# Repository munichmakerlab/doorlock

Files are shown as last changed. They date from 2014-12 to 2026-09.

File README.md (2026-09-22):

# MuMaLab DoorLock

## Schema

```
                      +----+                                        
                      |    |                          +-----------+
                      |    |                          | RFID      | 
                      |    |                       +--+ Reader    | 
                      |    |                       |  +-----------+ 
  +--------------+    |    |    +---------------+  |                
  |              |    |    |    |               |  |  +-----------+ 
  | RaspberryPi  +----(UART)----+  Arduino      +--+--+ Keypad    | 
  |              |    |    |    |   (frontend)  |  |  +-----------+ 
  +------+-------+    |    |    +---------------+  |                
         |            |    |                       |  +-----------+ 
         |            |    |                       +--+ Display   | 
   +-----+------+     |    |                          +-----------+ 
   | Door lock  |     |    |                                        
   +------------+     |    |                                        
                      +----+                                        
```

## Doorlock editor

There is a terminal-based (TUI) management tool available as well. Check out the dedicated repository for details: [doorlock-edit](https://github.com/munichmakerlab/doorlock-edit)

## Database Management CLI

The backend ships with `backend/manage_db.py`, a small CLI helper around the `doorlock.db` SQLite database. It creates the schema on first run (by executing `doorlock.db.sql`) and offers person/token lifecycle tooling that mirrors the firmware expectations.

### Running the tool

``` bash
python backend/manage_db.py <entity> <action> [arguments]
```

- `entity`: `person` or `token`
- `action`: subcommand listed below
- Output is logged to stdout/stderr; tables leverage `prettytable`

### Person actions

| Action | Arguments | Description |
| --- | --- | --- |
| `create` | `name`, `group_id` | Adds a new member with `disabled=0` after ensuring the name is unique. |
| `remove` | `name` | Deletes the person record (and their tokens via FK constraints if configured). |
| `list` | – | Shows active and inactive members plus token counts using textual tables. |
| `enable` / `disable` | `name` | Toggles the `disabled` flag to allow/deny door access. |
| `rename` | `old_name`, `new_name` | Renames a person once uniqueness is verified. |
| `show` | `name` | Prints status (“ENABLED”/“DISABLED”) and enumerates stored tokens. |

Examples:

``` bash
# Create an active member in group 2
python backend/manage_db.py person create "Ada Lovelace" 2

# Disable temporary access
python backend/manage_db.py person disable "Ada Lovelace"
```

### Token actions

Tokens live on the `dl_tokens` table and are always tied to an existing person. PINs are stored as `sha256("<token>:<pin>")` hashes.

| Action | Arguments | Description |
| --- | --- | --- |
| `add` | `person`, `token`, `pin` | Verifies ownership, checks for duplicates, and inserts a token/PIN pair. |
| `reset` | `person`, `pin` | Re-hashes the stored PIN for the person’s sole token (multi-token reset is intentionally rejected). |
| `remove` | `token` | Removes the token entry after confirming it exists. |

Examples:

``` bash
# Link a RFID tag to Ada with PIN 0420
python backend/manage_db.py token add "Ada Lovelace" 12345678 0420

# Rotate the PIN for the only token Ada owns
python backend/manage_db.py token reset "Ada Lovelace" 8642
```

### Operational notes

- The script logs to the `manage_db` logger; use `--log-level DEBUG` via `PYTHONLOGGING` env if deeper tracing is required.
- Tables are auto-created the first time the script runs if `doorlock.db` is missing the required schema.
- Always run the CLI from the repository root so relative paths to `doorlock.db` and `doorlock.db.sql` resolve correctly.

## Membership Sync CLI

You can export a csv of the existing members by going to the google drive, "Finanzen und Mitglieder" -> "Mitglieder" and make sure you're on the first page of the sheet. Put that csv on the doorlockpi and run the script. The helper [backend/prune_cancelled_members.py](backend/prune_cancelled_members.py) enforces that `doorlock.db` only contains people from this csv, removing stragglers who should no longer have access.

### Usage

``` bash
python backend/prune_cancelled_members.py [--db path/to/doorlock.db] [--csv path/to/members.csv] [--dry-run] [--yes]
```

- Reads the CSV, builds full names (`Vorname` + `Name`), and treats that set as the source of truth.
- Prints members that appear in the CSV but not the database (for awareness) and highlights the active database entries that will be disabled. Already disabled members are ignored so they do not clutter the diff.
- Name matching is case-insensitive and normalizes umlauts/ß (`Söhnen` matches `Soehnen`, `Groß` matches `Gross`).
- When run without `--dry-run` or `--yes`, launches an interactive selector: use the arrow keys to move, `space` to toggle entries, and `Enter` to confirm.
- Use `--yes` to skip the selector and disable all stale members automatically.
- On confirmation it flips `dl_persons.disabled` to `1` for the selected entries (tokens remain but are unusable because the person is disabled).

## Rename Members CLI

For ad-hoc name corrections, use [backend/rename_members.py](backend/rename_members.py).

``` bash
python backend/rename_members.py [--db path/to/doorlock.db]
```

- TTY-only curses UI showing all members with status and token counts.
- Navigate with arrows, press `f` to search by name (case-insensitive), press `space` on a highlighted entry to rename: you will be prompted (outside the UI) for new last name, then first name, then confirmation showing old → new.
- If the name is unchanged or already taken, nothing is updated. Successful renames write directly to `dl_persons` and return you to the list.

Typical workflow:

``` bash
# Inspect differences without deleting
python backend/prune_cancelled_members.py --dry-run

# Apply the deletions after review
python backend/prune_cancelled_members.py --yes
```

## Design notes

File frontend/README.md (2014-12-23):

# Doorlock Frontend
Arduino-based frontend for the MuMaLab hackerspace doorlock.

It's supposed to use a LCD, a 3x4 keypad and a RFID reader. That's too much pins for the Arduino Uno, so for now, there's no LCD. Instead, display output is send to the serial port, which will later also be used for communication with the backend.

## Libraries
* RFID Reader: https://github.com/miguelbalboa/rfid
* Keypad: http://playground.arduino.cc/code/Keypad

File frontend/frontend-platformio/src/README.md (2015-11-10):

# Doorlock Frontend
Arduino-based frontend for the MuMaLab hackerspace doorlock.

It's supposed to use a LCD, a 3x4 keypad and a RFID reader.

## Libraries
* RFID Reader: https://github.com/miguelbalboa/rfid
* Keypad: https://github.com/Chris--A/Keypad

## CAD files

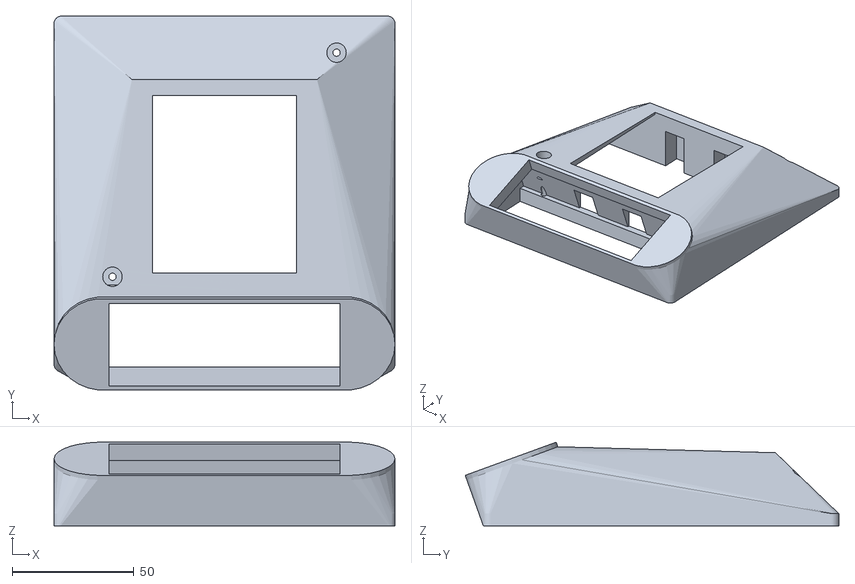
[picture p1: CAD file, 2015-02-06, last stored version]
OpenSCAD/EntrySystem.stl
140.0 x 153.4 x 34.3

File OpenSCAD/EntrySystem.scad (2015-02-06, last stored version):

$fn=30;

module visor(xdim, zdim, rdim) {
	hull() {
		translate([rdim, rdim, 0]) cylinder(r=rdim,h=zdim);
		translate([xdim-rdim,rdim,0]) cylinder(r=rdim,h=zdim);
	}
}

module baseplate(xdim_base,ydim_base,zdim_base,rdim_base) {	
	hull() {
		visor(xdim_base,zdim_base,rdim_base);
		translate([0,ydim_base,0]) visor(xdim_base,zdim_base,rdim_base);
	}
}

module keypad_part(xdim,ydim,zdim,length) {
	translate([length/2-xdim/2,length/2-ydim/2,0]) cube([xdim,ydim,zdim]);
}

module basebody() {
	hull() {
		hull() {
			baseplate(length,length,5,3);
			rotate([20,0,0]) visor(length,20,20);
		}
		keypad_part(76,100,30,length);
	}
	rotate([20,0,0]) visor(length,22,20);
}

module mounting_points() {
	translate([length/2-old_plate[0]/2,length/2-old_plate[1]/2+15,-1]) {
		cube(old_plate);
		
		translate([15,15,-10]) {
			cylinder(r=1.5,h=100);
			translate([0,0,30])
			cylinder(r=4,h=100);	
		}
	
		translate([old_plate[0]-15,old_plate[1]-15,-10]) {
			cylinder(r=1.5,h=100);	
			translate([0,0,25])
			cylinder(r=4,h=100);	
		}
	}
}

module rfid_reader() {
	
	rotate([-6,-40,0])
	translate([7,45,-25])
	cube([40,70,30]);

}

module rfid_hull(length) {
	color("red"){ 
		hull() {
			translate([7,43,0])
			cube([2,70.5,8]);
		
			translate([38.5,43,0])
			cube([2,70.5,2]);
		
			translate([40.5,43,27])
			cube([2,70.5,2]);
		}

		hull() {
			translate([length-7,43,0])
			cube([2,70.5,8]);
		
			translate([length-38.5,43,0])
			cube([2,70.5,2]);
		
			translate([length-40.5,43,27])
			cube([2,70.5,2]);
		}

	}
}


module display_cable_pipe() {
	translate([110,50,-1])
	rotate([90,0,0])
	cylinder(r=7,h=20);
}


length = 140;
keypad_size = [59,73,100];
keypad_mounting_space = [45,92,21];
keypad_mounting_space_center = [20,92,21];

display_size = [95,36,100];
display_mounting_space = [120,38,35.5];

old_plate = [122,122,1];

difference() {
	union() {
		difference() {
			basebody();
			translate([length/2-keypad_size[0]/2,length/2-keypad_size[1]/2+7,0]) cube(keypad_size);
		
			difference() {
				translate([length/2-keypad_mounting_space[0]/2,length/2-keypad_mounting_space[1]/2+7,0]) cube(keypad_mounting_space);
				translate([length/2-keypad_mounting_space_center[0]/2,length/2-keypad_mounting_space_center[1]/2+7,0]) cube(keypad_mounting_space_center);
			}
		
			translate([length/2-display_size[0]/2,2,0]) rotate([20,0,0]) translate([0,0,-20])
			cube(display_size);
		
			translate([length/2-display_mounting_space[0]/2,2,0]) rotate([20,0,0]) translate([0,0,-20])
			cube(display_mounting_space);
		
		}
	
	translate([0,36.5,0])
	cube([length,4,8]);
	}

	rfid_hull(length-2);
	mounting_points();
	//display_cable_pipe();	
}
	

	

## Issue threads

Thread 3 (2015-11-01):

Space open, but door locked -> Press key to open

tiefpunkt, 2015-11-01:
With the kids running in the hallway, and playing with our door, the current modus operandi is to just completely lock the door. This sort of contradicts our openness, so here's a different approach:

* We implement a third state of the door, let's call it "SEMI_LOCKED".
* Even though the space is technically open, the door remains locked.
* The door will unlock, when you press a certain key on the pinpad.
* The display shows a message reflecting this, and give instructions as to what to do to enter the space.

-> Kids won't be able to open the door as easy.
-> But still, people even without a token can come in easily.

peterfroehlich, 2015-11-02:
The "E" Button is still without a function (I wanted to implement a door
bell) and could be used for that...
Msg: "Press friEnd, and enter"
;-)

-P

2015-11-01 23:40 GMT+01:00 Severin Schols <notifications@github.com>:

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

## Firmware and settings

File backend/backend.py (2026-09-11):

#!/usr/bin/env python3
import sqlite3
import serial
from threading import Timer
import logging
import hashlib
import os.path
from time import sleep
from datetime import datetime, timedelta
from sys import exit
import paho.mqtt.client as paho

import config

DIR = os.path.dirname(os.path.realpath(__file__))

# config
DATABASE = DIR + '/doorlock.db'
SERIAL_PORTS = ['/dev/ttyUSB0', '/dev/ttyUSB1', '/dev/ttyUSB2', '/dev/ttyUSB3']
DEBUG = False
LOG_FILENAME = DIR + "/doorlock.log"
LOG_LEVEL = logging.INFO
PONG_TIMEOUT = 30  # in sec

if os.path.exists("COM8"):
    SERIAL_PORT = 'COM8'
    DEBUG = True

# regular ping to frontend, every 10 seconds, 30 sec timeout
running = True


def ping():
    if not running:
        return
    ser.write(b"PING;\n")
    ser.flush()
    timer = Timer(10.0, ping)
    timer.start()


def statusChange():
    if lock.isUnlocked():
        ser.write(b"STATUS,1;\n")
        mqttc.publish(config.topic, "1", 1, True)
    else:
        ser.write(b"STATUS,0;\n")
        mqttc.publish(config.topic, "0", 1, True)
    ser.flush()


def feedback(topic, state):
    mqttc.publish("%s/%s" % (config.feedback_topic, topic), str(state), 1, False)


def create_hash(text):
    h = hashlib.sha256()
    h.update(text.encode("utf-8"))
    return h.hexdigest()


def ring_doorbell():
    logger.info("Ring Ring")


def serial_connect():
    for serial_port in SERIAL_PORTS:
        if os.path.exists(serial_port):
            logger.info("Using serial port %s" % serial_port)
            return serial.Serial(serial_port, timeout=6)
    logger.error("No valid serial port found. Sleeping and retrying...")
    sleep(60)
    return serial_connect()


# MQTT functions
def on_connect(client, userdata, flags, reason_code, properties=None):
    logging.info("Connect with RC " + str(reason_code))


def on_disconnect(client, userdata, flags, reason_code, properties=None):
    logging.warning("Disconnected (RC " + str(reason_code) + ")")
    if reason_code != 0:
        try_reconnect(client)


# MQTT reconnect
def try_reconnect(client, time=60):
    try:
        logging.info("Trying reconnect")
        client.reconnect()
    except Exception:
        logging.warning("Reconnect failed. Trying again in " + str(time) + " seconds")
        Timer(time, try_reconnect, [client]).start()


# get logger
logging.basicConfig(format='%(asctime)s - %(name)s - %(levelname)s - %(message)s', level=LOG_LEVEL,
                    filename=LOG_FILENAME)
logger = logging.getLogger("doorlock")
logger.info("Starting doorlock backend")

# instantiate db connection
conn = sqlite3.connect(DATABASE)
c = conn.cursor()
logger.debug("Database opened")

# connect to serial port
ser = serial_connect()
logger.debug("Serial port to frontend opened")

# initialize MQTT
logging.info("Initializing MQTT")
mqttc = paho.Client(paho.CallbackAPIVersion.VERSION2, "mumalab_doorlock")
mqttc.username_pw_set(config.broker["user"], config.broker["password"])
mqttc.will_set(config.topic, "?", 1, True)
mqttc.on_connect = on_connect
mqttc.on_disconnect = on_disconnect
try:
    mqttc.connect(config.broker["hostname"], config.broker["port"], 60)
except Exception as e:
    logger.error("Failed to connect to MQTT! Got exception: %s" % str(e))
mqttc.loop_start()

# lock implementation
if DEBUG:
    from simlock import SimLock
    lock = SimLock()
else:
    # from motorlock import MotorLock
    # lock = MotorLock()
    from zuko_wifi_lock import ZukoLock
    lock = ZukoLock()

lock.onStatusChange += statusChange
lock.onFeedback += feedback

# start pinging frontend
last_successful_ping = datetime.now()
ping()


while True:
    try:
        a = ser.readline()
        if not a:
            if last_successful_ping + timedelta(seconds=PONG_TIMEOUT) < datetime.now():
                logger.warning("Got no PONG from Arduino from %d sec, reinitializing serial port" % PONG_TIMEOUT)
                try:
                    ser.close()
                except Exception as e:
                    logger.error("Failed to close serial port! Got exception: %s" % str(e))
                ser = serial_connect()
                ping()
                last_successful_ping = datetime.now()
            continue

        line = a.decode("ascii", errors="replace")
        b = line.rstrip("\n\r;").split(",")

        if b == ["PONG"]:
            last_successful_ping = datetime.now()
            logger.debug("Got Pong...(%s)" % (str(last_successful_ping)))
        else:
            logger.debug(b)

        # Unlock command: "UNLOCK,<token>,<pin>;"
        # Reply with "ACK;" or "NAK;"
        if b[0] == "UNLOCK":
            t = (b[1], create_hash(b[1] + ":" + b[2]))
            c.execute(
                'SELECT p.name from dl_tokens t JOIN dl_persons p ON t.person_id = p.id WHERE t.token=? AND t.pin=? AND p.disabled =0',
                t)
            r = c.fetchone()
            if r is not None:
                logger.warning("Valid unlock request by %s (%s)", r[0], t[0])
                ser.write(b"ACK;\n")
                lock.unlock()
            else:
                logger.error("Invalid unlock request (%s, %s)", t[0], b[2])
                ser.write(b"NAK;\n")
            ser.flush()

        elif b[0] == "RING":
            ring_doorbell()

        # Lock command "LOCK;"
        elif b[0] == "LOCK":
            logger.warning("Lock request")
            lock.lock()

        # reply to ping: "PONG;"
        elif b[0] == "PONG":
            if lock.isUnlocked():
                ser.write(b"STATUS,1;\n")
            else:
                ser.write(b"STATUS,0;\n")
            ser.flush()

    except serial.serialutil.SerialException:
        logger.error("Serial adapter disconnected! Sleeping and trying to reconnect...")
        sleep(10)
        ser = serial_connect()

    except KeyboardInterrupt:
        print("Received keyboard interrupt. Stopping...")
        running = False
        break

    except Exception as e:
        logger.error(e)
        exit(99)

logger.info("Stopping doorlock backend")
mqttc.loop_stop()
mqttc.disconnect()

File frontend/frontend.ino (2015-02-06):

/* Typical pin layout used:
 * ------------------------------------------------------------
 *             MFRC522      Arduino       Arduino   Arduino
 *             Reader/PCD   Uno           Mega      Nano v3
 * Signal      Pin          Pin           Pin       Pin
 * ------------------------------------------------------------
 * RST/Reset   RST          9             5         D9
 * SPI SS      SDA(SS)      10            53        D10
 * SPI MOSI    MOSI         11 / ICSP-4   51        D11
 * SPI MISO    MISO         12 / ICSP-1   50        D12
 * SPI SCK     SCK          13 / ICSP-3   52        D13
 */

#include "states.h"

#include <SPI.h>
#include <MFRC522.h>

#define RST_PIN		9		// 
#define SS_PIN		10		//

MFRC522 mfrc522(SS_PIN, RST_PIN);	// Create MFRC522 instance

#include <Keypad.h>

const byte ROWS = 4; //four rows
const byte COLS = 3; //three columns
char keys[ROWS][COLS] = {
  {'7','8','9'},
  {'4','5','6'},
  {'1','2','3'},
  {'x','0','P'}
};
byte rowPins[ROWS] = {5, 4, 3, 2}; //connect to the row pinouts of the keypad
byte colPins[COLS] = {8, 7, 6}; //connect to the column pinouts of the keypad

Keypad keypad = Keypad( makeKeymap(keys), rowPins, colPins, ROWS, COLS );

#include <LiquidCrystal.h>
LiquidCrystal lcd(A3, A2, A1, A0, A5, A4);

States state = LOCKED;
long timeout_start = 0;
long timeout = 10000;

String serial_buffer = "";
String serial_unfinished_line = "";
String buffer = "";

int Epin = A7;

void updateDisplay() {
  lcd.clear();
  if (state == LOCKED) {
    lcd.print("You shall not pass! ");
    lcd.setCursor(0, 1);
    lcd.print("                    ");
  } else if (state == PIN_ENTRY) {
    lcd.print("Enter PIN & press P ");
    lcd.setCursor(0, 1);
    for (int i = 0; i < buffer.length(); i++) {
      lcd.print("*");
    }
  } else if (state == WAIT_FOR_UNLOCK) {
    lcd.print("Waiting for         ");
    lcd.setCursor(0, 1);
    lcd.print("       confirmation ");
  } else if (state == INVALID_PIN) {
    lcd.print("  > Invalid PIN <   ");
    lcd.setCursor(0, 1);
    lcd.print("> Please try again <");
  } else if (state == UNLOCKED) {
    lcd.print("It's open...        ");
    lcd.setCursor(0, 1);
    lcd.print("Just come on in! =) ");
  }
}

bool timeoutExpired() {
  return (millis() - timeout_start > timeout);
}

void resetTimeout() {
  timeout_start = millis();
}

void setState(States new_state) {
  state = new_state;
  buffer = "";
  updateDisplay();
  resetTimeout();
}

bool checkE() {
 if (analogRead(Epin) < 1000) {
   return true;
 }
 return false;
} 

void callRing() { 
  
  Serial.print("RING;");
  
  lcd.clear();
  lcd.print("Ding     Ding     Ding     Ding     Ding");
  lcd.setCursor(5, 1);
  lcd.print("Dong     Dong     Dong     Dong");
  
  for (int positionCounter = 0; positionCounter < 20; positionCounter++) {
    lcd.scrollDisplayLeft();
    delay(200);
  }
  
  updateDisplay();
}

void setup() {
  lcd.begin(20, 2);
  lcd.print("Booting....");
  delay(500);
  
  Serial.begin(9600);		// Initialize serial communications with the PC
 
  SPI.begin();			// Init SPI bus
  mfrc522.PCD_Init();		// Init MFRC522
  
  updateDisplay();
}


void loop() {
  if (Serial.available() > 0) {
    byte incomingByte = Serial.read();
    if (incomingByte == '\n') {
      if (serial_unfinished_line == "PING;") {
        Serial.println("PONG;");
      } else if (serial_unfinished_line.startsWith("STATUS,")) {
        String tmp = serial_unfinished_line.substring(7,8);
        if (tmp == "0") {
          if (state == UNLOCKED) {
            setState(LOCKED);
          }
        } else if (tmp == "1") {
          if (state != UNLOCKED) {
            setState(UNLOCKED);
          }
        }
      } else {
        serial_buffer = serial_unfinished_line;
      }
      serial_unfinished_line = "";
    } else {
      serial_unfinished_line += (char)incomingByte;
    }
  }
    
  if (state == LOCKED) {
    if ( checkE() ) {
      callRing();
    }
    
    // Look for new cards
    if ( ! mfrc522.PICC_IsNewCardPresent()) {
      return;
    }
    // Select one of the cards
    if ( ! mfrc522.PICC_ReadCardSerial()) {
      return;
    }
    mfrc522.PICC_HaltA();
    
    buffer = "";
    setState(PIN_ENTRY);
    
  } else if (state == PIN_ENTRY) {  
    char key = keypad.getKey();
    
    if (key) {
      if (key == 'P' || key == 'E') {
        Serial.print("UNLOCK,");
        char tmp[16];
        for (byte i = 0; i<mfrc522.uid.size; i++) {
          sprintf(tmp,"%.2X",mfrc522.uid.uidByte[i]);
          Serial.print(tmp);
        }
        Serial.print(",");
        Serial.print(buffer);
        Serial.print(";");
        Serial.println();
        setState(WAIT_FOR_UNLOCK);        
      } else {
        buffer += key;
        updateDisplay();
        timeout_start = millis();
      }
    } else {
      if (timeoutExpired()) {
        setState(LOCKED);
      }
    }
  } else if (state == WAIT_FOR_UNLOCK) {
    if (serial_buffer != "") {
      if (serial_buffer == "ACK;") {
        setState(UNLOCKED);
      } else {
        setState(INVALID_PIN);
      }
      serial_buffer = "";
    } else if (timeoutExpired()) {
      setState(LOCKED);
    }
  } else if (state == UNLOCKED) {
    if ( checkE() ) {
      callRing();
    }
    
    char key = keypad.getKey();
    
    if (key) {
      if (key == 'P' || key == 'E') {
        if (buffer == "0") {
          Serial.println("LOCK;");
          setState(LOCKED);
        }        
      } else {
        buffer += key;
        timeout_start = millis();
      }
    } else if (buffer.length() > 0 && timeoutExpired()) {
      buffer = "";
    }
  } else if (state == INVALID_PIN) {
    char key = keypad.getKey();
    if (key) {
      setState(PIN_ENTRY);
      buffer += key;
      updateDisplay();
    } else if (timeoutExpired()) {
      setState(LOCKED);
    }
  } else {
    Serial.println("state not implemented");
    delay(1000);
  }
}

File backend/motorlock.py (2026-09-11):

from eventhook import EventHook
import logging
import RPi.GPIO as GPIO
from time import sleep


class MotorLock():
    def __init__(self):
        self.PIN_FDBK_SVP = 23
        self.PIN_FDBK_STEUERFALLE = 24
        self.PIN_FDBK_DOOR = 8
        self.PIN_FDBK_ERROR = 7
        self.onFeedback = EventHook()
        self.locked = True
        self.onStatusChange = EventHook()
        self.logger = logging.getLogger("motorlock")
        GPIO.setwarnings(False)
        GPIO.setmode(GPIO.BCM)
        GPIO.setup(4, GPIO.OUT)
        GPIO.setup(18, GPIO.OUT)
        # GPIO.setup(17, GPIO.IN)
        # GPIO.setup(21, GPIO.IN)
        # GPIO.add_event_detect(17, GPIO.FALLING, callback=self.button_callback, bouncetime=1000)
        # GPIO.add_event_detect(21, GPIO.FALLING, callback=self.button_callback, bouncetime=1000)

        GPIO.setup(self.PIN_FDBK_SVP, GPIO.IN, pull_up_down=GPIO.PUD_UP)
        GPIO.setup(self.PIN_FDBK_STEUERFALLE, GPIO.IN, pull_up_down=GPIO.PUD_UP)
        GPIO.setup(self.PIN_FDBK_DOOR, GPIO.IN, pull_up_down=GPIO.PUD_UP)
        GPIO.setup(self.PIN_FDBK_ERROR, GPIO.IN, pull_up_down=GPIO.PUD_UP)

        GPIO.add_event_detect(self.PIN_FDBK_SVP, GPIO.BOTH, callback=self.feedback_callback, bouncetime=300)
        GPIO.add_event_detect(self.PIN_FDBK_STEUERFALLE, GPIO.BOTH, callback=self.feedback_callback, bouncetime=300)
        GPIO.add_event_detect(self.PIN_FDBK_DOOR, GPIO.BOTH, callback=self.feedback_callback, bouncetime=300)
        GPIO.add_event_detect(self.PIN_FDBK_ERROR, GPIO.BOTH, callback=self.feedback_callback, bouncetime=300)

        self.locked = (GPIO.input(4) == GPIO.LOW)
        self.logger.info("Locked?: %s" % self.locked)

    def feedback_callback(self, channel):
        self.logger.debug("GPIO feedback interrupt called on channel " + str(channel))
        topic = "unknown"
        state = GPIO.input(channel)
        if channel == self.PIN_FDBK_SVP:
            topic = "svp"
        elif channel == self.PIN_FDBK_STEUERFALLE:
            topic = "steuerfalle"
        elif channel == self.PIN_FDBK_DOOR:
            topic = "door"
        elif channel == self.PIN_FDBK_ERROR:
            topic = "error"

        self.onFeedback.fire(topic=topic, state=state)

    def button_callback(self, channel):
        self.logger.debug("GPIO button interrupt called on channel " + str(channel))
        sleep(1)
        if GPIO.input(channel) == GPIO.HIGH:
            self.logger.debug("Bounce")
            return

        if channel == 17:
            self.logger.warning("Lock button pressed")
            self.lock()
        elif channel == 21:
            self.logger.warning("Unlock button pressed")
            self.unlock()

    def lock(self):
        if self.locked:
            self.logger.warning("already locked")
            return
        self.logger.info("locking...")
        self.locked = True
        GPIO.output(4, GPIO.LOW)
        GPIO.output(18, GPIO.HIGH)
        self.onStatusChange.fire()

    def unlock(self):
        if not self.locked:
            self.logger.warning("already unlocked")
        self.logger.info("unlocking...")
        self.locked = False
        GPIO.output(4, GPIO.HIGH)
        GPIO.output(18, GPIO.LOW)
        self.onStatusChange.fire()

    def isUnlocked(self):
        return not self.locked

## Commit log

2014-12-30 Proper lock implementation, interrupt handling
2015-01-01 motorlock implementation
2015-01-02 more functions in manage_db, hash PIN, debug mode
2015-01-19 motor lock check state after restart
2015-02-06 Added 3D models for doorpanal
    [EntrySystem.scad, EntrySystem.stl]
2015-02-14 Increase resiliance to crash of usb adapter
    [backend.py]
2015-02-22 Add timeout to catch failing serial port
    [backend.py]
2015-04-26 add functionality to reset pin
2015-11-09 move semi timeout to backend, trigger with switch
2015-11-10 fixing the arduino code to make it compile
    [frontend.ino]
2016-10-16 fix timeout issue when typing pin
    [backend.py, frontend.ino]
2026-09-11 Adding the latest files from the RPi and cleanup of repo
    [EntrySystem.scad, EntrySystem.stl]
2026-10-27 Comment out all MQTT related code since it's currently not needed
